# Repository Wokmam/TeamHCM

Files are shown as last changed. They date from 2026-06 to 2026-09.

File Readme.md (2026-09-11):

# 🤖 Team Born To Win - WRO Future Engineers

¡Bienvenidos al repositorio oficial de nuestro equipo! Aquí documentamos todo el desarrollo, código, diseño y avances para nuestra participación.

## 📸 Conoce al Equipo

<p align="center">
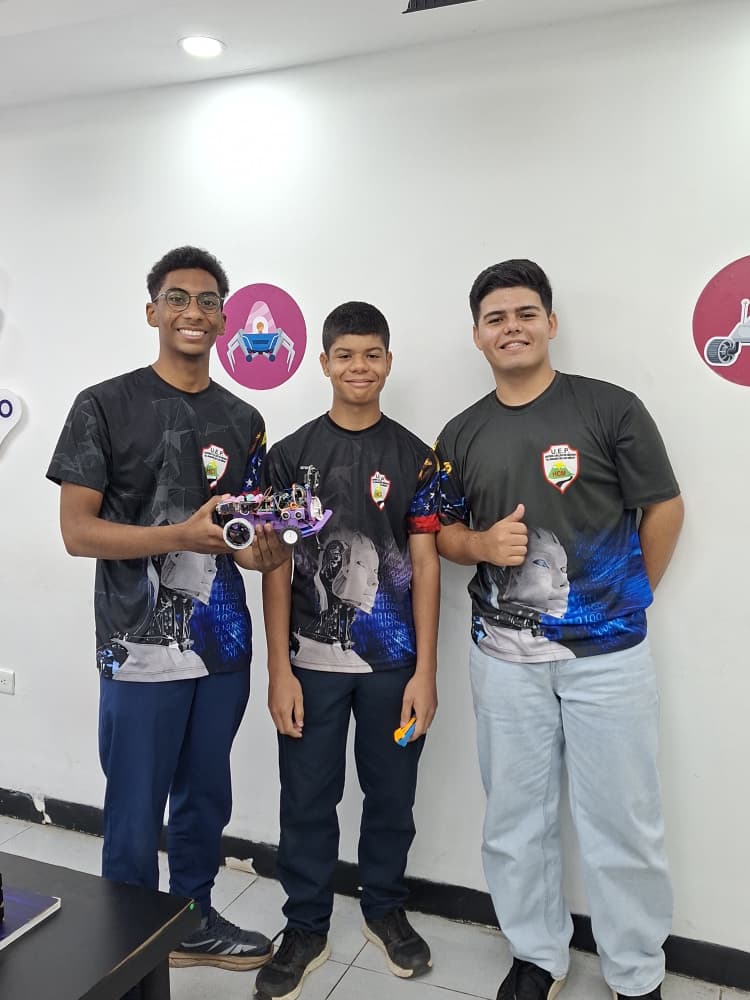
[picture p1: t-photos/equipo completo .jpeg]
Equipo completo Team HCM
  
</p>

 <p align="center">
  somos estudiantes de diferentes edades que nos reunimos con el objetivo de competir en la competencia WRO futuros ingenieros con nuestro proyecto
 </p> 
 
 ## Nuestro Equipo

<table align="center">
  <tr>
    <td align="center" width="33%">
      <h3>Carlos Armijo</h3>
      <p><b>Edad:</b> 17 años</p>
      <p><b>Rol:</b> Lógica de programación y estrategias</p>
    </td>
    <td align="center" width="33%">
      <h3>Julio Noguera</h3>
      <p><b>Edad:</b> 14 años</p>
      <p><b>Rol:</b> Gestión de GitHub, control de actualizaciones y estrategia</p>
    </td>
    <td align="center" width="33%">
      <h3>Miguel Salas</h3>
      <p><b>Edad:</b> 18 años</p>
      <p><b>Rol:</b> Mecánica, diseño 3D y electrónica</p>
    </td>
  </tr>
</table>

> *Puedes ver más detalles e imágenes en la carpeta [t-photos](t-photos/).*

# Índice de Contenidos — Team Born To Win (WRO Future Engineers)

1. [Presentación del Equipo](#1-presentación-del-equipo)
2. [World Robot Olympiad (WRO)](#2-world-robot-olympiad-wro)
3. [Arquitectura General del Sistema](#3-arquitectura-general-del-sistema)
4. [Sistema de Tracción (Tren Trasero)](#4-sistema-de-tracción-tren-trasero)
5. [Sistema de Dirección (Tren Delantero)](#5-sistema-de-dirección-tren-delantero)
6. [Diseño Estructural e Impresión 3D del Chasis](#6-diseño-estructural-e-impresión-3d-del-chasis)
7. [Sistema Electrónico y Sensores](#7-sistema-electrónico-y-sensores)
8. [Desafíos de la Competencia](#8-desafíos-de-la-competencia)
9. [Partes del Código (Firmware)](#9-partes-del-código-firmware)
10. [Lista de Componentes](#10-lista-de-componentes)

---

<h2>2. World Robot Olympiad (WRO)</h2>
<p align="center">
{4F88DD0A-A459-4292-9581-5FD236E6E98C}
</p>
World Robot Olympiad™ es una competencia temática en donde equipos de niños y jóvenes entre 8 y 22 años de edad medirán sus conocimientos, aplicando soluciones a problemas del mundo real, utilizando la Metodología STEAM, de la mano de la robótica educativa.<p>
<p>Dentro de la WRO, la categoría Futuros Ingenieros destaca por su enfoque práctico y evolutivo. Su objetivo principal es conectar a los estudiantes con los retos reales de la industria a través de la automatización. Al exigir un pensamiento analítico, esta división moldea a los líderes tecnológicos del mañana, transformando el conocimiento teórico en innovación pura.<p>

El desafío central de este año se enfoca en la conducción autónoma. Diseñar un coche capaz de tomar decisiones por sí mismo lleva la robótica educativa al siguiente nivel, forzando a los participantes a dominar herramientas de última generación y aportando un nivel de ingeniería y dinamismo.

<h2>Secciones</h2>

## 1. Arquitectura General del Sistema
El vehículo utiliza una configuración de **Tracción Trasera (RWD)** combinada con un sistema de **Dirección Delantera**. Esta disposición emula el comportamiento de un automóvil real.
<p align="center">
aa
</p>

## 2. Sistema de Tracción (Tren Trasero)

El tren trasero es el encargado de proveer el torque y velocidad necesarios para el desplazamiento del vehículo. Está compuesto por un motor principal y un mecanismo diferencial.

### 2.1. Actuador Principal: Motor DC con Encoder (600 RPM)
Para la propulsión se seleccionó un motor de corriente continua (DC) equipado con un encoder de cuadratura.
<table>
  <tr>    
    <td width="40%" align="center" valign="middle" bgcolor="#0d1117">
      51+JncrV17L _SX522_-removebg-preview
    </td>
    <td width="60%" valign="middle" bgcolor="#0d1117">
      <h3>Especificaciones:</h3>
      <ul>
        <li><strong>Voltaje Nominal:</strong> 12V</li>
        <li><strong>Velocidad:</strong> 600 RPM</li>
        <li><strong>Tipo de Encoder:</strong> Encoder de cuadratura (Efecto Hall) de fase A y B con 120 PPR en el eje de salida</li>
      </ul>
    </td>
  </tr>
</table>

* **Motivos de Selección:**
    * **Cálculo de Odometría:** El propósito fundamental del encoder es la odometría. Al contar los pulsos generados por las vueltas del motor, el firmware calcula con precisión cuántos centímetros ha avanzado el vehículo en la pista. Esto nos permite programar desplazamientos basados en distancias exactas.

### 2.2. Caja de Engranajes y Sistema Diferencial
La potencia del motor no va directo a las ruedas; pasa a través de una etapa de reducción y se distribuye mediante un diferencial mecánico.

<p align="center">
WhatsApp Image 2026-06-25 at 2 18 30 PM
</p>

* **Mecanismo Diferencial:** Se diseñó e implementó un diferencial de engranajes cónicos en el eje trasero.
* **Motivos de Selección e Implementación:**
    * **Impreso en 3D:** Todo el conjunto del mecanismo diferencial ha sido fabricado mediante impresión 3D utilizando filamento **PETG**. Se seleccionó este material debido a su alta resistencia al impacto y durabilidad superior frente al PLA.
    * **Rodamientos:** Para soportar el movimiento del diferencial, se integraron rodamientos. Estos ayudan a evitar atascos mecánicos, reducir la fricción y permitir un giro mucho más suave y eficiente del eje.
    * **Evitar derrapes:** En las curvas, la rueda interior recorre una distancia menor que la rueda exterior. Sin un diferencial, una de las ruedas se vería obligada a patinar, provocando pérdida de tracción y descalibración de la odometría basada en el encoder.

## 3. Sistema de Dirección (Tren Delantero)
En el sistema de dirección, la precisión es vital para que el robot no se desvíe de los ángulos deseados y mantenga trayectorias repetibles.
  
### 3.1. Actuador de Dirección: Servomotor
El control angular de las ruedas delanteras se realiza mediante un servomotor de alta precisión conectado a una geometría de dirección.

<table>
  <tr>    
    <td width="40%" align="center" valign="middle" bgcolor="#0d1117">
    bb0c992e-8172-4063-9124-5125c4acf2e3 __CR0_0_300_300_PT0_SX300_V1___-removebg-preview
    </td>
    <td width="60%" valign="middle" bgcolor="#0d1117">
      <h3>Especificaciones:</h3>
      <ul>
        <li><strong>Tipo:</strong> Digital</li>
        <li><strong>Velocidad:</strong> 0.12 sec/60° (4.8V)</li>
        <li><strong>Torque:</strong> 1.8 kg-cm (4.8V)</li>
        <li><strong>Voltaje:</strong> 5V</li>
        <li><strong>Rango de Operación:</strong> 0°-180°</li>
      </ul>
    </td>
  </tr>
</table>

* **Motivos de Selección:**
    * **Control de Posición preciso:** A diferencia de un motor DC común, el servomotor permite definir un ángulo exacto.
    * **Tipo de servomotor:** Se seleccionó específicamente un servomotor con piñonería metálica en lugar de uno con engranajes de plástico. En pruebas previas, los componentes de plástico experimentaban un desgaste excesivo debido al estrés mecánico, lo que provocaba un aumento crítico en la temperatura del actuador y fallos por rotura de dientes. Los engranajes metálicos ofrecen la tolerancia al torque y la disipación térmica necesarias para soportar las exigencias.

### 3.2. Geometría de Dirección (Principio de Ackerman)
El varillaje mecánico de la dirección delantera está diseñado siguiendo geométricamente el principio de **Ackerman**.

<p align="center">
parte delantera del carro
</p>

* **Justificación Técnica:**
    * **Estructura Impresa en 3D:** Al igual que el tren trasero, las varillas y las manguetas de la dirección están fabricados totalmente mediante impresión 3D en **PETG**.
    * **Rodamientos en Ruedas Delanteras:** Para mejorar la fluidez del movimiento, se incorporaron rodamientos en ambas ruedas delanteras. Esto disminuye la fricción al rodar, asegurando que las llantas delanteras giren mucho mejor y respondan mejor a los cambios de dirección.

### 4. Diseño Estructural e Impresión 3D del Chasis
La plataforma base del robot fue diseñada en Fusion360 completamente a medida y fabricada en su totalidad mediante impresión 3D utilizando filamento PETG. lo que le otorga una alta resistencia a los impactos y durabilidad.

El diseño en 3D conecta directamente los soportes impresos en 3D 
para el portabaterías, la PCB principal y los sensores ultrasónicos. Toda la unión de estos soportes, componentes electrónicos y sensores al chasis se realiza mediante tornillos. Esto asegura una fijación firme que evita vibraciones o desajustes.

<p align="center">
vehicle-botton
</p>

<table>
  <thead>
    <tr>
      <th align="center">Dimensión</th>
      <th align="left">Valor (CM)</th>
    </tr>
  </thead>
  <tbody>
    <tr>
      <td align="center" valign="middle">Largo</td>
      <td align="left" valign="middle">25</td>
      </td>
    </tr>
    <tr>
      <td align="center" valign="middle">Ancho</td>
      <td align="left" valign="middle">16.8</td>
      </td>
    </tr>
    <tr>
      <td align="center" valign="middle">Alto</td>
      <td align="left" valign="middle">10</td>
      </td>
    </tr>
  </tbody>
</table>

## 5. Sistema Electrónico y Sensores
Este apartado abarca la arquitectura electrónica del vehículo y los componentes seleccionados para la gestión de tareas y percepción del entorno.

<p align="center">
Esquema_conexiones
</p>

<hr style="border: none; border-top: 5px solid #30363d; margin: 20px 0;">

## Unidad de Procesamiento: Arduino Mega Pro Mini
Como placa de desarrollo seleccionamos el Arduino Mega Pro Mini, que se encarga de la lectura de sensores y la genereación de señales para los actuadores.

Se seleccionó esta variante específica debido a su de forma sumamente reducida en comparación con el Arduino Mega convencional, lo que permite integrarlo de manera eficiente en el chasis sin comprometer espacio ni añadir peso innecesario. A pesar de su tamaño compacto, conserva la totalidad de pines digitales y analógicos del microcontrolador ATmega2560, ofreciendo la conectividad necesaria para gestionar múltiples sensores y actuadores de forma simultánea. Asimismo, su diseño plano facilita soldarle pines header macho para conectarlo a pines header hembra conectaods en nuestra PCB personalizada, eliminando el uso de cables propensos a falsos contactos por las vibraciones del coche. Todo esto se complementa con una excelente relación costo-beneficio, asegurando un hardware potente, fiable y económico para el desarrollo del proyecto.

En la arquitectura de nuestro sistema, el Arduino Mega Pro Mini funciona como el cerebro del robot, procesando las entradas del sistema de visión ESP32-CAM, la IMU de 6 ejes MPU-6050 y tres sensores de Ultrasonidos HC-SR04, al tiempo que ejecuta algoritmos y genera salidas de control precisas para el controlador de motor y el ServoMotor.

<table>
  <tr>    
    <td width="40%" align="center" valign="middle" bgcolor="#0d1117">
    ard-removebg-preview
    </td>
    <td width="60%" valign="middle" bgcolor="#0d1117">
      <h3>Especificaciones:</h3>
      <ul>
        <li><strong>Microcontrolador:</strong> ATmega2560</li>
        <li><strong>Consumo mA:</strong> 20mA</li>
        <li><strong>Entradas Analógicas:</strong> 16</li>
        <li><strong>Pines Digitales E/S:</strong> 54 (de los cuales 15 son salidas PWM)</li>
        <li><strong>Voltaje de Operación:</strong> 5V</li>
      </ul>
    </td>
  </tr>
</table>

<hr style="border: none; border-top: 5px solid #30363d; margin: 20px 0;">

## 5.2. Sensores de Distancia: Ultrasonidos HC-SR04

El cálculo de las distancias hacia los límites de la pista se gestiona mediante un conjunto de sensores de ultrasonidos HC-SR04 ubicados de forma estratégica en la parte frontal del coche. Estos componentes operan emitiendo una ráfaga de ondas acústicas de alta frecuencia que viajan por el aire hasta reflejarse en las superficies fijas del entorno y regresar al receptor. A través del tiempo que tarda este eco en retornar, el microcontrolador calcula con gran precisión la distancia en centímetros hacia los muros.

<p align="center">
Gemini_Generated_Image_czb582czb582czb5
</p>

En la lógica de navegación de nuestro coche, el sensor central se encarga de monitorizar el espacio libre al frente, lo que resulta crítico para identificar la aproximación hacia las paredes frontales de la pista. Por su parte, los dos sensores laterales evalúan la proximidad de los muros izquierdo y derecho. La integración conjunta de estas tres lecturas permite al firmware saber en qué salida se encuentra para ejecutar una ruta ya hecha. Al estar atornillados con firmeza en los soportes impresos en 3D que están puestos en el chasis, se garantiza que los ángulos de apertura inferiores a 15° se mantengan estables y libres de las vibraciones propias del motor.

<table>
  <tr>    
    <td width="40%" align="center" valign="middle" bgcolor="#0d1117">
      descarga-removebg-preview (1)
    </td>
    <td width="60%" valign="middle" bgcolor="#0d1117">
      <h3>Especificaciones Técnicas:</h3>
      <ul>
        <li><strong>Voltaje de operación:</strong> 5V</li>
        <li><strong>Rango de medición:</strong> 2 cm a 400 cm</li>
        <li><strong>Precisión:</strong> ±3 mm</li>
        <li><strong>Ángulo de apertura:</strong> Menor a 15°</li>
        <li><strong>Corriente de trabajo:</strong> 15 mA</li>
      </ul>
    </td>
  </tr>
</table>

<hr style="border: none; border-top: 5px solid #30363d; margin: 20px 0;">

## 5.3. Unidad de Medición Inercial (IMU): MPU6050
La estabilidad angular y la orientación espacial del vehículo están reguladas por la unidad de medición inercial MPU6050. Este dispositivo integra un giroscopio de tres ejes y un acelerómetro de tres ejes en un único chip, permitiendo capturar con precisión los cambios de velocidad y las variaciones en la rotación del coche sobre la pista. La comunicación con el microcontrolador central se realiza de manera eficiente a través del protocolo I2C, lo que asegura una transmisión rápida de los datos inerciales recolectados en tiempo real.

<p align="center">
images
</p>

La implementación de la IMU es fundamental para el sistema de navegación del vehículo, ya que cumple la función de corregir las desviaciones en la trayectoria recta. Aunque los encoders del motor miden los centímetros avanzados, factores físicos como el deslizamiento de las llantas o las imperfecciones del suelo pueden hacer que el carro pierda el rumbo. El MPU6050 monitorea constantemente el ángulo de guiñada (*yaw*), detectando cualquier giro involuntario y permitiendo que el firmware realice ajustes inmediatos en el servomotor de dirección para contrarrestar el desvío y mantener al robot alineado perfectamente con la pista.

<table>
  <tr>    
    <td width="40%" align="center" valign="middle" bgcolor="#0d1117">
      mpu6050_3-axis_acceleration_gyroscope_6dof_module_2-removebg-preview
    </td>
    <td width="60%" valign="middle" bgcolor="#0d1117">
      <h3>Especificaciones Técnicas:</h3>
      <ul>
        <li><strong>Voltaje de Operación:</strong> 3.3V - 5.0V</li>
        <li><strong>Grados de Libertad:</strong> 6 ejes (3 ejes acelerómetro, 3 ejes giroscopio)</li>
        <li><strong>Rango del Giroscopio:</strong> ±250, ±500, ±1000, ±2000 °/seg</li>
        <li><strong>Rango del Acelerómetro:</strong> ±2g, ±4g, ±8g, ±16g</li>
        <li><strong>Protocolo de Comunicación:</strong> I2C</li>
      </ul>
    </td>
  </tr>
</table>

**Conexión electrónica**

**Arreglo de alimentación y consumo**
Estamos trabajando con 4 baterías en una conexión mixta, con lo cual nos referimos a que están conectadas en serie y en paralelo. Vamos a llamar al primer grupo de baterías como Grupo A y a las otras dos baterías como Grupo B. Las dos baterías de cada grupo están conectadas entre sí en paralelo, y luego el Grupo A y el Grupo B están conectados en serie. Esto nos proporciona una corriente de 4 A, equivalente a 4000 mA, y un voltaje de 8 V.

Tenemos un regulador de voltaje elevador y reductor o *step-up/down*, el cual es muy práctico ya que permite subir y bajar el voltaje. El elevador está conectado desde el polo positivo y el negativo de las baterías. Desde este mismo positivo donde se alimenta el elevador existe un nodo conectado a un regulador de 5 V, y desde este regulador alimentamos el Arduino Mega Pro Mini. Además, contamos con un interruptor ubicado en la línea positiva que controla el encendido de todos los componentes.

**Etapa de potencia y actuadores**
El elevador de voltaje está ajustado a 12 V. Desde esos 12 V que ofrece el elevador alimentamos el módulo puente H L298N. La salida del puente H está conectada a un motor DC con encoder. En el Arduino tenemos conectados los pines de control IN1 e IN2, mientras que el pin ENA está conectado al pin 8 del Arduino. Usamos el pin 8 por ser un pin PWM, lo que nos permite modificar el ancho de pulso y así ajustar la velocidad del motor según sea necesario.

<p align="center">
  l298n
</p>

Tenemos dos LED: uno rojo y uno azul. El ánodo del LED rojo está conectado al pin 5 del Arduino y el ánodo del LED azul está conectado al pin 9. Ambos LED tienen su cátodo conectado a GND, que es el polo negativo del Arduino. También tenemos conectado un servomotor MG90S con engranajes metálicos, el cual proporciona un torque mayor al SG90 tradicional. Este servo está conectado al pin 7 del Arduino, que es un pin PWM. El servomotor se alimenta desde el regulador de 5 V que alimenta al Arduino, desde donde sale un nodo.

**Sensores y componentes adicionales**
Tenemos conectados los sensores de ultrasonidos a los lados y en el centro. El sensor del lado izquierdo está conectado a los pines 31 y 30, el del centro a los pines 27 y 29, y el del lado derecho a los pines 23 y 25.

También tenemos un giroscopio conectado al pin 20 para la línea SDA y al pin 21 para la línea SCL. Contamos con un pulsador normalmente abierto conectado al pin 28 del Arduino en configuración *pull-down*. Finalmente, hay un capacitor de 1000 microfaradios en el servomotor y otro de 470 microfaradios en el Arduino Mega Pro Mini.

<p align="center">
  hc-sr04
</p>

<h2>🎯 Desafíos de la Competencia</h2>
<table align="center" width="100%">
  <tr>
    <td width="50%" align="center" valign="top" bgcolor="#0d1117">
      <br>
      <h3>🔗 Desafío Abierto</h3>
      <a href="https://youtu.be/Df2YxnnMeV0?si=AwDFZAtFiafpjhe3">
        Open Challenge Roun
      </a>
      <br><br>
      <a href="https://youtu.be/Df2YxnnMeV0?si=AwDFZAtFiafpjhe3">Ver Ronde de Desafío Abierta</a>
      <br><br>
      <p><i>Navegación autónoma mediante IMU y sensores de distancia para completar vueltas y estacionamiento de de forma precisa</i></p>
    </td>
    <td width="50%" align="center" valign="top" bgcolor="#0d1117">
      <br>
      <h3>🔗 Desafío de Obstaculos</h3>
      <a href="URL">
        Obstacle Challenge Round
      </a>
      <br><br>
      <a href="URL">Ronda de Desafío Cerrada</a>
      <br><br>
      <p><i>Cumbia</i></p>
    </td>
  </tr>
</table>

<h2>Partes del codigo</h2>

## control de los motores

```cpp

#define ENA 8
#define IN1 4
#define IN2 6
int velocidadMotor = 255;

void setup() {
  pinMode(ENA, OUTPUT);
  pinMode(IN1, OUTPUT);
  pinMode(IN2, OUTPUT);
}

void loop() {
  digitalWrite(IN1, HIGH);
  digitalWrite(IN2, LOW);
  analogWrite(ENA, velocidadMotor);
}
```
esta parte del codigo se encarga de controlar el  motor para despues integrarlo a las variables 

## control del servo motor y giroscopio
```cpp
#include <Wire.h>
#include <MPU6050_tockn.h>
#include <Servo.h>

#define PIN_SERVO 7
MPU6050 mpu(Wire);
Servo myservo;
float yaw, setpoint = 0, centroServo = 82, Kp = 0.8;

void setup() {
  Wire.begin(); mpu.begin(); myservo.attach(PIN_SERVO);
  myservo.write(centroServo);
}

void loop() {
  mpu.update();
  yaw = mpu.getAngleZ();
  float error = setpoint - yaw;
  float salida = Kp * error;
  int anguloServo = constrain(centroServo + salida, 71, 93);
  myservo.write(anguloServo);
}
```
esta parte del codigo se encarga de ubicar el sentido del carro para hacer que en las variables puedan girar gracias al servo motor

# Sistema de Ultrasonidos (NewPing)

El robot utiliza **tres sensores ultrasónicos** gestionados a través de la librería `NewPing` para medir distancias de manera eficiente, detectar posiciones de referencia en la pista y asistir en el centrado lateral dentro de los pasillos.

## 📌 Pines de Conexión

| Sensor | Definición en Código | Pin Trigger (Trig) | Pin Echo (Echo) | Descripción / Función |
| :--- | :--- | :--- | :--- | :--- |
| **Izquierdo** | `IZ` | `31` | `30` | Medición lateral izquierda y cálculo de error de centrado. |
| **Medio (Frontal)** | `FE` | `27` | `29` | Detección frontal de obstáculos y control de distancia de frenado. |
| **Derecho** | `DE` | `23` | `25` | Medición lateral derecha y cálculo de error de centrado. |

* **Distancia Máxima Configurada:** `400 cm` (`Max_Dist` definido por `#define Max_Dist 400`).

---

## ⚙️ Funciones Principales

### 1. Actualización No Bloqueante (`actualizarDistancias`)
Para evitar que las demoras de los pulsos ultrasónicos detengan la ejecución del bucle principal y afecten la lectura de la IMU y los motores, las lecturas se actualizan mediante un intervalo de tiempo controlado por `millis()`:
* **Intervalo de muestreo:** `20 ms` (`const int intervaloPing = 20`).
* **Variables globales actualizadas:** `distIz`, `distDe` y `distFe`.

```cpp
void actualizarDistancias() {
  if (millis() - ultimoPing >= intervaloPing) {
    distIz = IZ.ping_cm();
    distDe = DE.ping_cm();
    distFe = FE.ping_cm();
    ultimoPing = millis();
  }
}
## pasos contados de los motores 

#define Clk 3
#define Dt 2
volatile long ticks = 0;
const float CM_POR_TICK = 0.01;

void setup() {
  //
  attachInterrupt(digitalPinToInterrupt(Clk), ENCODER, CHANGE);
}

void ENCODER() {
  int A = digitalRead(Clk); int B = digitalRead(Dt);
  // Lógica de cuadratura para sumar/restar ticks
  if (A == 1) ticks += (B == 0) ? 1 : -1; 
}

float obtenerDistanciaCm() {
  long t; noInterrupts(); t = ticks; interrupts();
  return t * CM_POR_TICK;
}
```
Con esta parte del codigo nos permite saber cuando girar ya que podemos calcular la distancia recorrida.

## funciones 
```cpp
void posicion1velocidad200() {
  float distancia = obtenerDistanciaCm();
  if (distancia >= 0 && distancia <= 22.56) {
    controlarServoIMU(); controlarMotor200();
    modoCentradoActivo = false; setpoint = 0; // Recta inicial
  } else if (distancia >= 22.56 && distancia <= 48.21) {
    controlarServoIMU(); controlarMotor200();
    modoCentradoActivo = false; setpoint = 180; // Curva
  } else if (distancia >= 48.21 && distancia <= 70.77) {
    controlarServoIMU(); controlarMotor200();
    modoCentradoActivo = true; setpoint = 180; // Curva centrando
  }

}
void posicion2velocidad200() { /* Intervalos y setpoints para ruta 2 */ }
void posicion3velocidad200() { /* Intervalos y setpoints para ruta 3 */ }
void posicion4adelante()       { /* Intervalos y setpoints para ruta 4 */ }
void posicion5adelante()       { /* Intervalos y setpoints para ruta 5 */ }
void posicion6adelante()       { /* Intervalos y setpoints para ruta 6 */ }
```

Esta parte del codigo tiene la capacidad de decidir que ruta hace el robot de pendiendo de los valores del  giroscopio y los sensores de ultra sonido.

## pulldown
```cpp
void loop() {
  if (pulldowm == 1) {
    if (estadoposinverso == 1) posicion1inverso();
 
  } else {
    if (estadopos == 1) posicion1velocidad200();

  }
}

void posicion1inverso() {
  float distancia = obtenerDistanciaCm();
  if (distancia >= 22.56 && distancia <= 48.21) {
    setpoint = -180; 
}
```
Esta parte del código permite hacer que el código pueda inicializar los proceso de ubicación y arranque del carro.
<h2>Lista de Componentes</h2>

<table>
  <thead>
    <tr>
      <th align="center">Cantidad</th>
      <th align="left">Nombre</th>
      <th align="center">Foto</th>
    </tr>
  </thead>
  <tbody>
    <tr>
      <td align="center" valign="middle">1</td>
      <td align="left" valign="middle">Arduino Mega Pro Mini</td>
      <td align="center">
        ard-removebg-preview
      </td>
    </tr>
    <tr>
      <td align="center" valign="middle">1</td>
      <td align="left" valign="middle">MPU6050</td>
      <td align="center">
        MPU6050
      </td>
    </tr>
    <tr>
      <td align="center" valign="middle">1</td>
      <td align="left" valign="middle">Puente H l298n</td>
      <td align="center">
        l298n
    </tr>
         <td align="center" valign="middle">1</td>
      <td align="left" valign="middle">esp32cam</td>
      <td align="center">
        esp32cam
        </td>
      </tr>
   </tr>
        <td align="center" valign="middle">3</td>
      <td align="left" valign="middle">hc-sr04</td>
      <td align="center">
        hc-sr04
        </td>
      </tr>
   </tr>
       <td align="center" valign="middle">1</td>
      <td align="left" valign="middle">motor dc con encoder</td>
      <td align="center">
        l298n 
      </td>
    </tr>
       <td align="center" valign="middle">1</td>
      <td align="left" valign="middle">mg90s</td>
      <td align="center">
        mg90s 
      </td>
    </tr>
       <td align="center" valign="middle">1</td>
      <td align="left" valign="middle">vaquelita perforada (15x9)</td>
      <td align="center">
        vaquelita perforada grande
      </td>
    </tr>
         <td align="center" valign="middle">1</td>
      <td align="left" valign="middle">led rojo</td>
      <td align="center">
        led rojo
      </td>
    </tr>
          <td align="center" valign="middle">1</td>
      <td align="left" valign="middle">led azul</td>
      <td align="center">
        led rojo
      </td>
    </tr>
           <td align="center" valign="middle">1</td>
      <td align="left" valign="middle">espadines macho</td>
      <td align="center">
        espadines macho
      </td>
    </tr>
             <td align="center" valign="middle">1</td>
      <td align="left" valign="middle">espadines hembras</td>
      <td align="center">
        espadines hembras
      </td>
    </tr>
              <td align="center" valign="middle">1</td>
      <td align="left" valign="middle">capacitor</td>
      <td align="center">
        capacitor
      </td>
    </tr>
               <td align="center" valign="middle">1</td>
      <td align="left" valign="middle">regulador de voltaje 5v</td>
      <td align="center">
        regulador
      </td>
    </tr>
      <tr>
      <td align="center" valign="middle">4</td>
      <td align="left" valign="middle">Baterias 18650</td>
      <td align="center">
        litio
      </td>
    </tr>
    <tr>
      <td align="center" valign="middle">1</td>
      <td align="left" valign="middle">Botón</td>
      <td align="center">
        button
      </td>
    </tr>
  </tbody>
</table>

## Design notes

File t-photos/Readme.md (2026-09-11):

# 👥 Conoce al Team HCM

¡Bienvenidos a la sección de fotos y miembros del equipo! Aquí presentamos oficialmente a los integrantes que hacen posible este proyecto para la competición **WRO Future Engineers**.

---

## 👨‍💻 Integrantes del Equipo

<table align="center">
  <tr>
    <td align="center" width="33%">
      <h3>Carlos Armijo</h3>
      <p><b>Edad:</b> 17 años</p>
      <p><b>Rol:</b> Lógica de programación y estrategias</p>
    </td>
    <td align="center" width="33%">
      <h3>Julio Noguera</h3>
      <p><b>Edad:</b> 14 años</p>
      <p><b>Rol:</b> Gestión de GitHub, control de actualizaciones y estrategia</p>
    </td>
    <td align="center" width="33%">
      <h3>Miguel Salas</h3>
      <p><b>Edad:</b> 18 años</p>
      <p><b>Rol:</b> Mecánica, diseño 3D y electrónica, programación</p>
    </td>
  </tr>
</table>

---

## 📸 Foto Oficial del Equipo

<p align="center">
  Equipo completo Team HCM
</p>

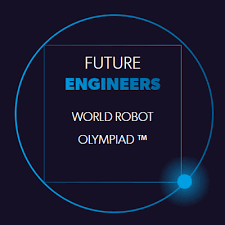
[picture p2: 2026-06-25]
images/WRO.png

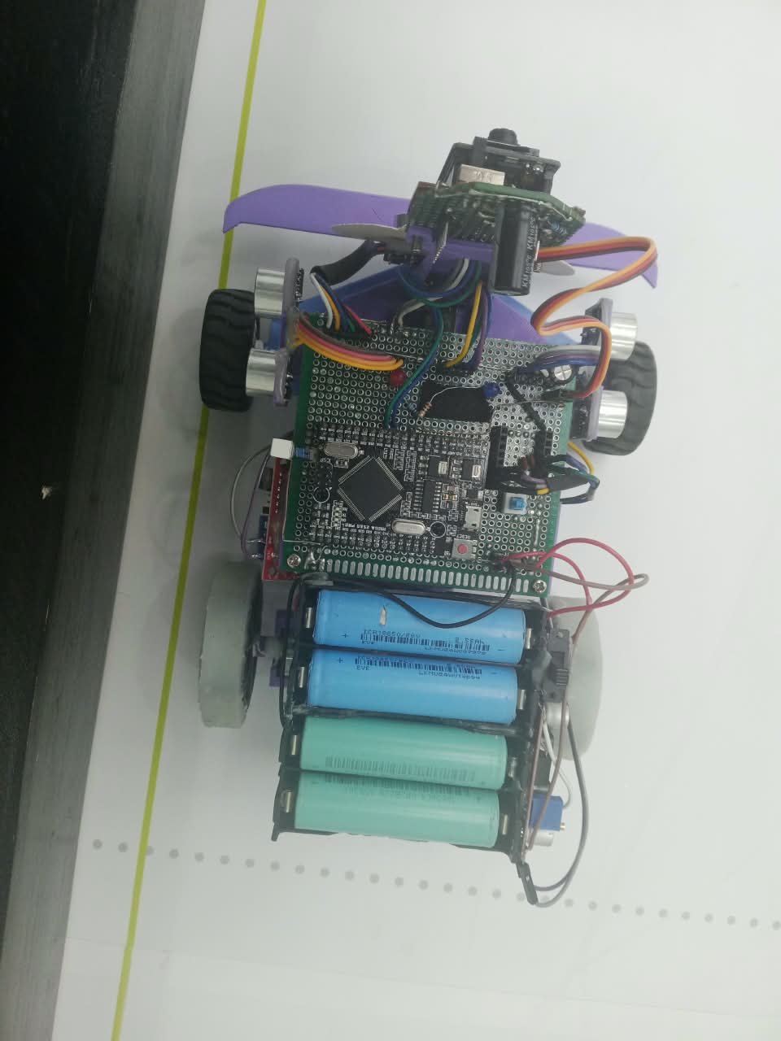
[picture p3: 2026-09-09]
v-photos/parte superior del carro.jpeg

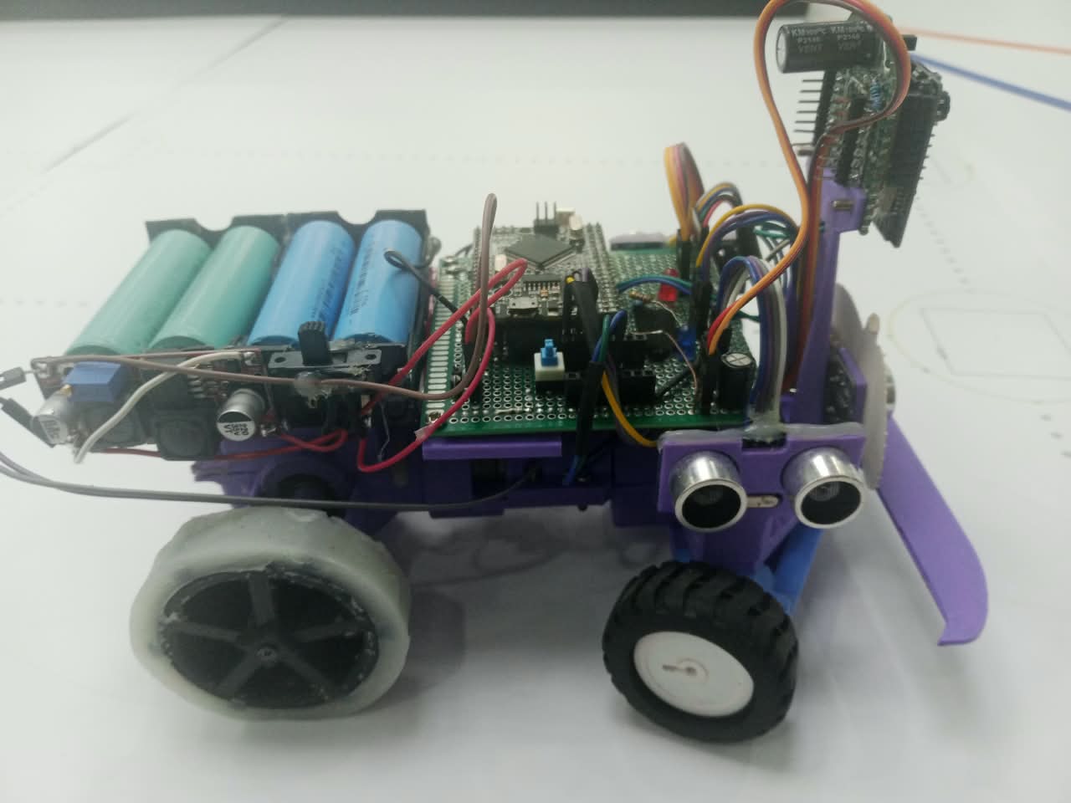
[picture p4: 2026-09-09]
v-photos/parte izquierda del carro.jpeg

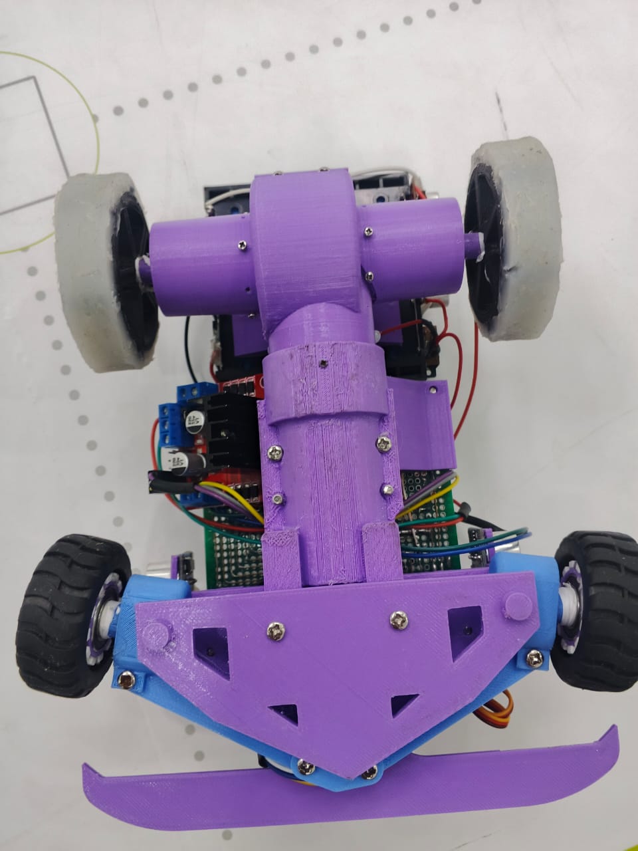
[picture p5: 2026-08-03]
v-photos/parte inferior del carro.jpeg

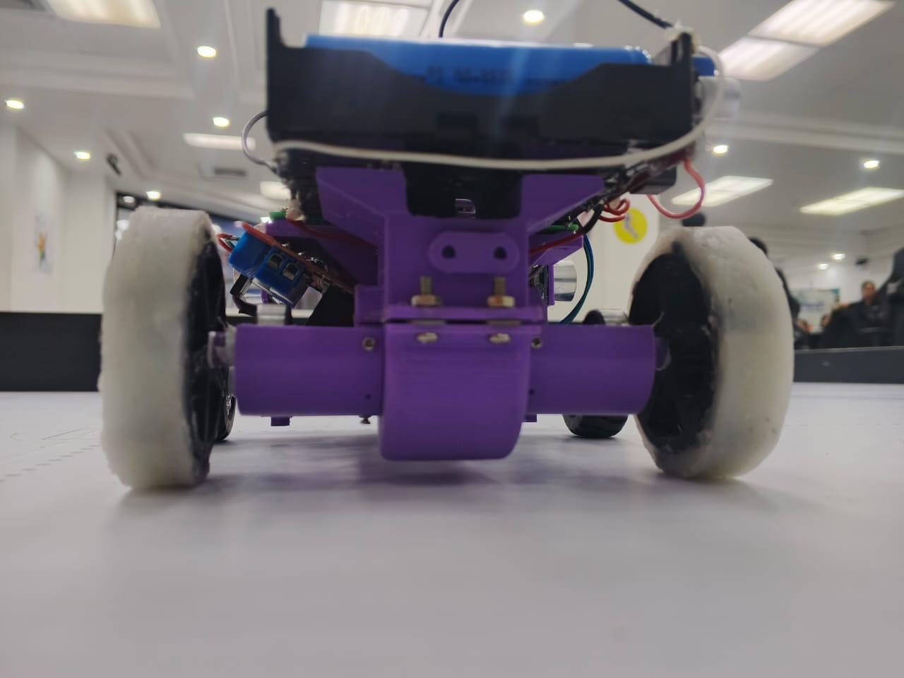
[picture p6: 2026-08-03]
v-photos/parte trasera del carro.jpeg

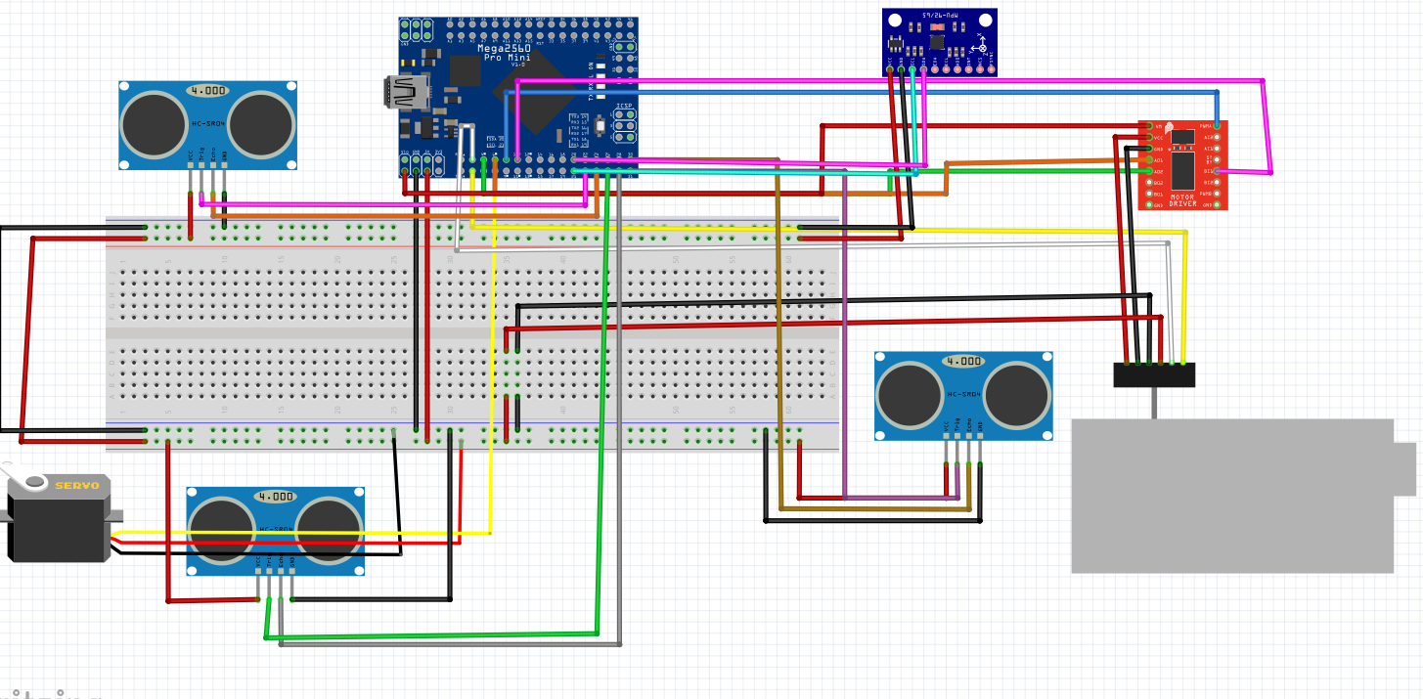
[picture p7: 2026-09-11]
Schemes/Captura de pantalla 2026-06-27 235005.png

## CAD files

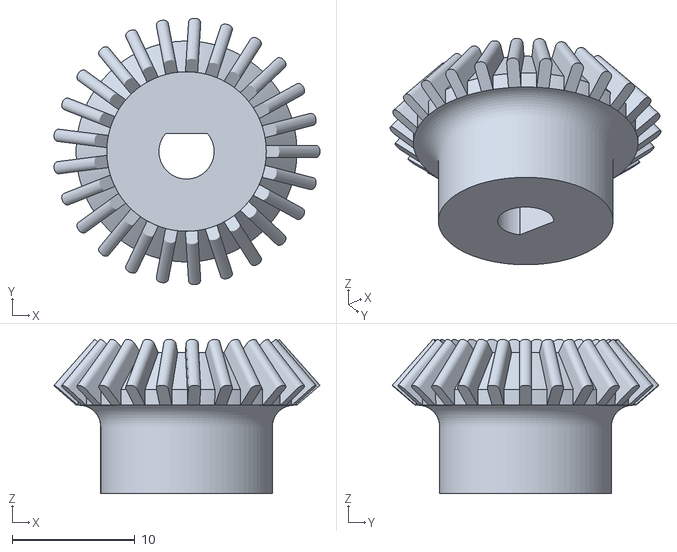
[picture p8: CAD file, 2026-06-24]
3D-Models/0.8.stl
21.7 x 21.7 x 12.6

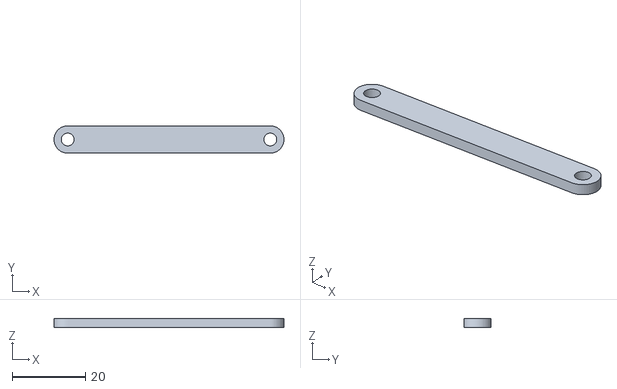
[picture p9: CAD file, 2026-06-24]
3D-Models/sujeta servo l.stl
63.0 x 7.50 x 2.40

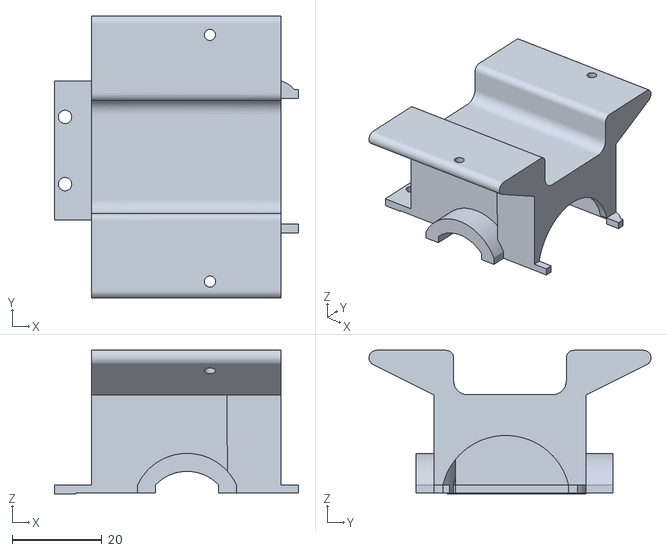
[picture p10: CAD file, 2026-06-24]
3D-Models/sosten bateria .stl
54.5 x 62.9 x 32.0

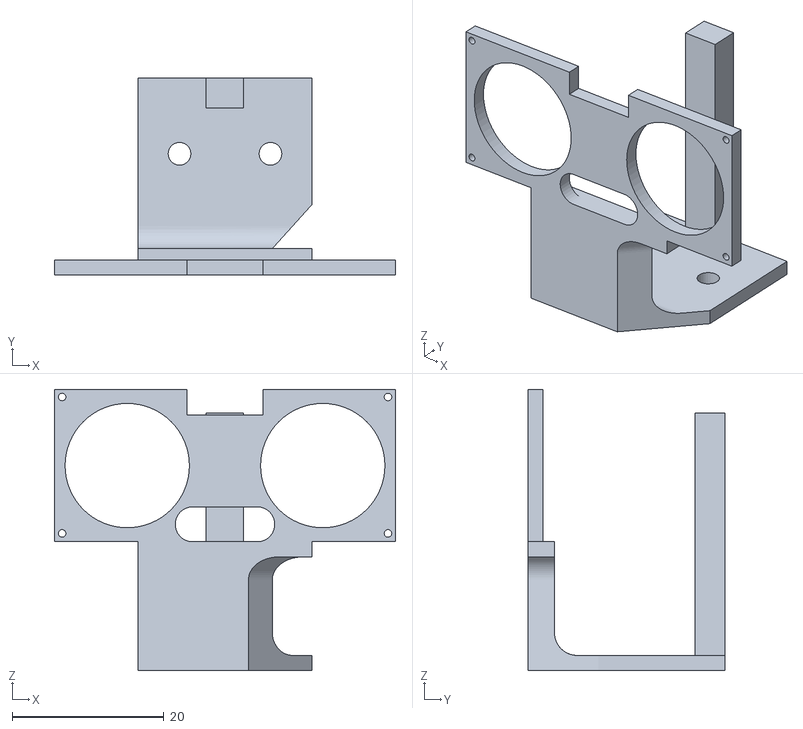
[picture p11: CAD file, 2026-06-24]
3D-Models/Soporte ultrasonido derecha.stl
45.0 x 26.0 x 37.1

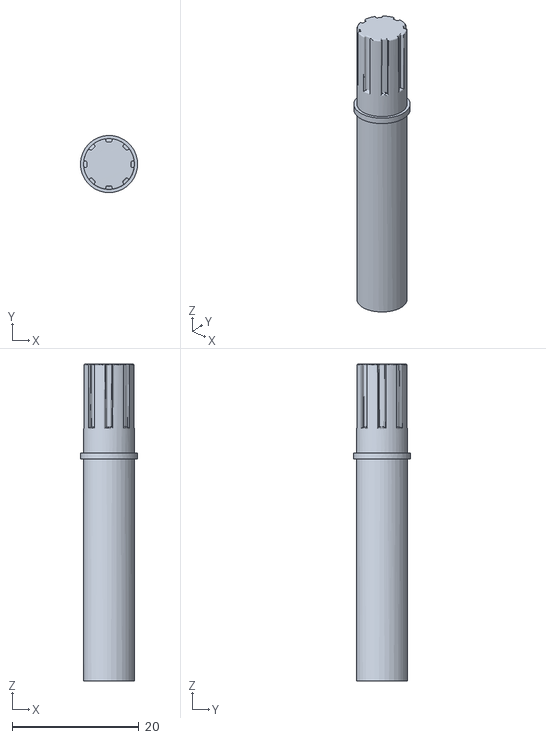
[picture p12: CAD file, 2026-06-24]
3D-Models/obj_2_AKS.STL.stl
9.00 x 9.00 x 50.0

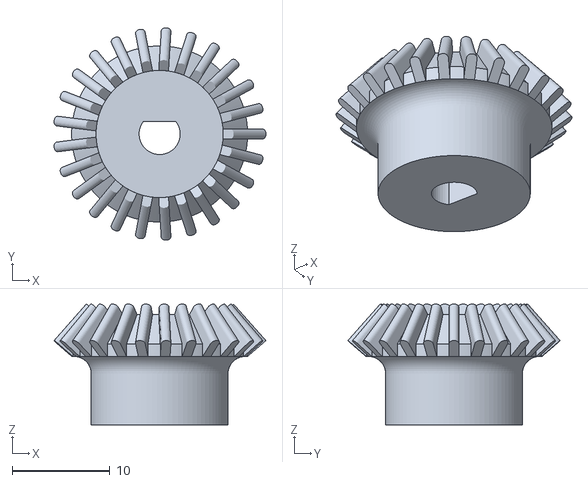
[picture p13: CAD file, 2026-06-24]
3D-Models/MECAP -1.stl
21.7 x 21.7 x 12.4

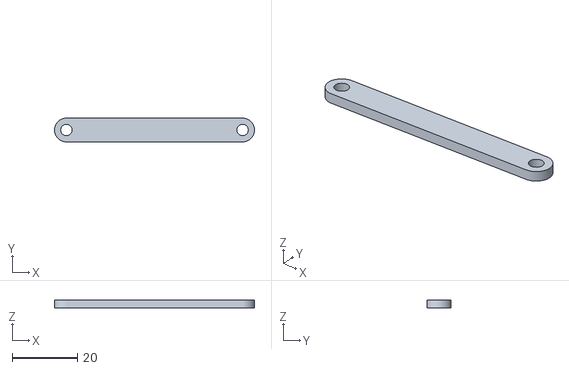
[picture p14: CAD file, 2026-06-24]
3D-Models/sujeta servo mas rueda.stl
61.3 x 7.30 x 2.40

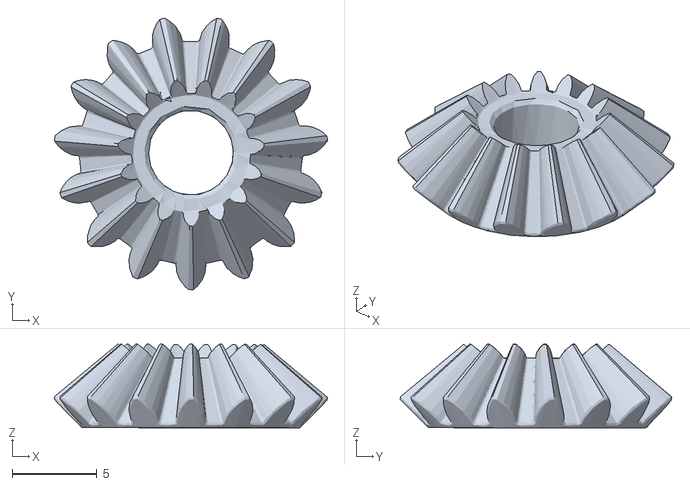
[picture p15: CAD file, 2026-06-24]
3D-Models/obj_6_PLANET DİŞLİ.STL.stl
16.1 x 16.1 x 4.96

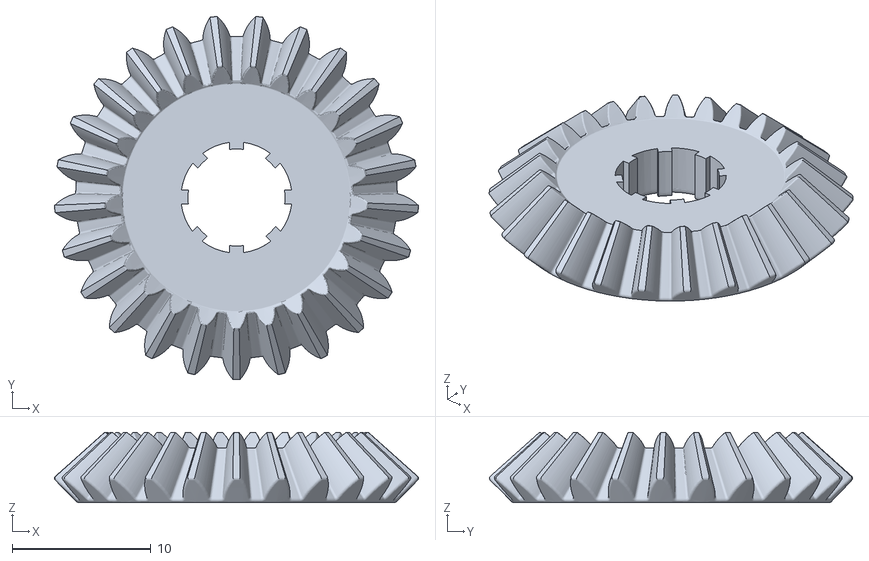
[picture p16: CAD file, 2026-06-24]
3D-Models/obj_7_YANAK DİŞLİSİ.STL.stl
26.2 x 26.2 x 5.06

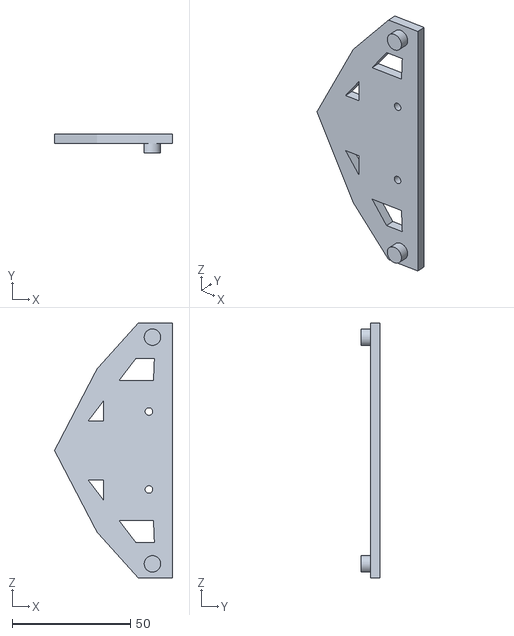
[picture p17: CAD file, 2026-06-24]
3D-Models/abajo servo.stl
50.0 x 8.00 x 108.0

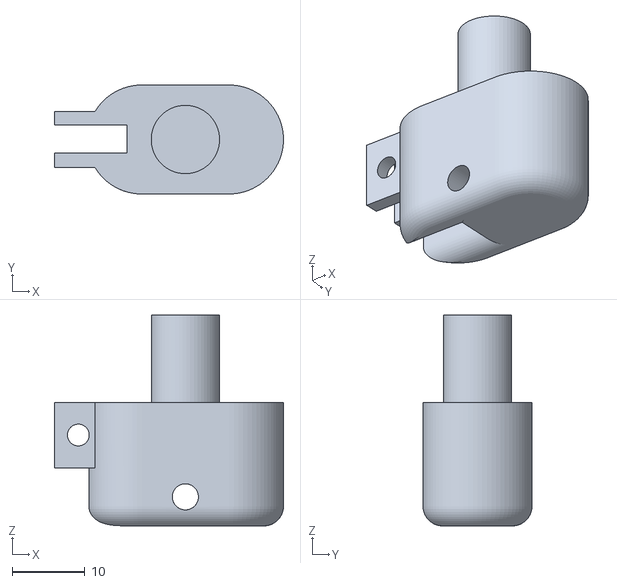
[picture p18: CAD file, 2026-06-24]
3D-Models/trn superior sosten is.stl
31.5 x 15.0 x 29.0

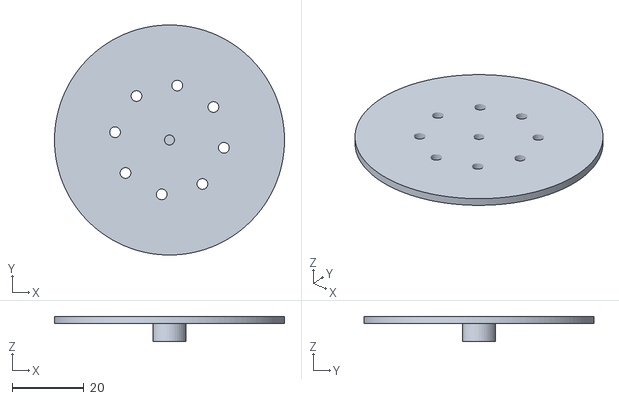
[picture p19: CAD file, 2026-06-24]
3D-Models/tapa molde wro.stl
64.2 x 64.2 x 7.00

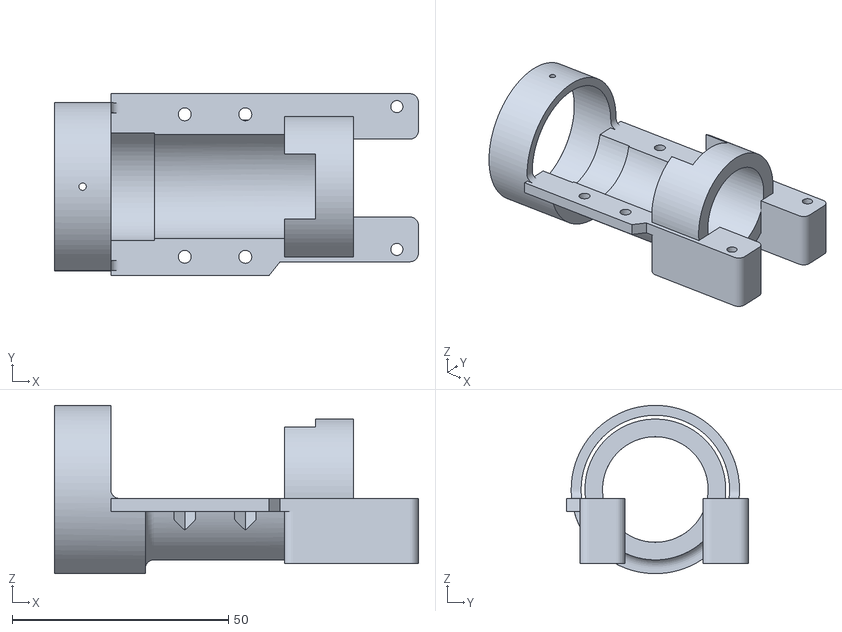
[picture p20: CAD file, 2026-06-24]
3D-Models/chasis central wro motor mas tren etc.stl
84.1 x 42.0 x 38.9

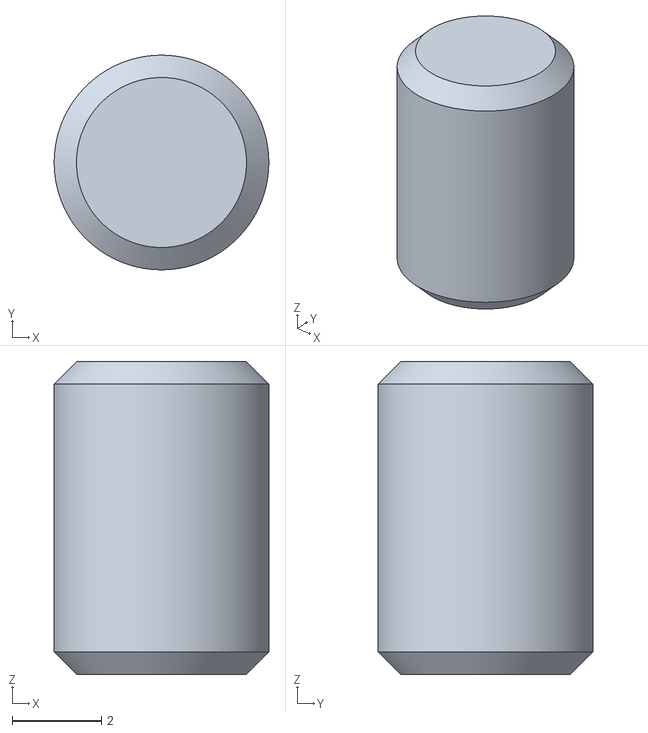
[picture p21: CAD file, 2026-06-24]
3D-Models/obj_9_pim.STL.stl
4.80 x 4.80 x 7.00

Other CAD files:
3D-Models/base bateria wro.stl
3D-Models/base de electronica.stl
3D-Models/chasis wro sosten de la mitad.stl
3D-Models/obj_11_pim.STL.stl
3D-Models/MACA PUNTA.stl
3D-Models/MACAP-1.5.stl
3D-Models/MECANISMO DEL MOTOR CON ENCODER PIESA DEL DIFERENCIAL (~recovered).f3d
3D-Models/MECANISMO DEL MOTOR CON ENCODER PIESA DEL DIFERENCIAL.stl
3D-Models/PORTA MOTOR.stl
3D-Models/PORTA MOTOR1.stl
3D-Models/PUNTA DEL MECANISMO.stl
3D-Models/Soporte Ultrasonido frontal.stl
3D-Models/base bateria wro v1.stl
3D-Models/base de la bateria wro.stl
3D-Models/bateria wro v2.stl
3D-Models/chasi9s parte de arriva .stl
3D-Models/chasis arriva servo.stl
3D-Models/dif largo sosten de rueda.stl
3D-Models/dif sosten dela rueda.stl
3D-Models/dif.stl
3D-Models/molde de la rueda tren delantero.stl
3D-Models/molde wro.stl
3D-Models/mpu6050wro.stl
3D-Models/obj_10_PLANET DİŞLİ.STL.stl
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

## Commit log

2026-06-25 Update Readme with product details and images
    Added product descriptions and images for Raspberry Pi and Logitech Webcam.
2026-06-25 Update image and specifications in Readme.md
    Updated image source and modified operating voltage description.
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2026-06-25 Revise N20 Motor Specifications in Readme
    Updated motor specifications in the documentation.
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2026-06-25 Revise motor selection reasons and odometry details
    Updated the selection reasons for the motor and added details about odometry calculation.
2026-06-25 Fix formatting of odometry calculation description
2026-06-25 Update Readme with motor specifications table
    Added specifications table for the DC motor with encoder.
2026-06-25 Modify image tag for motor specifications
    Updated image tag in Readme.md to remove height attribute.
2026-06-25 Enhance Readme with components table
    Added a table with components and their descriptions, including images for Raspberry Pi 4, MPU6050, and H-Bridge TB6612FNG.
2026-06-25 Update Raspberry Pi image and clean up Readme
    Updated the Raspberry Pi image and removed unnecessary lines from the table.
2026-06-25 Adjust image size for Raspberry Pi 4 in README
    Updated image dimensions for Raspberry Pi 4 Model B in the README.
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2026-06-25 Adjust image size in Readme.md
    Updated image size in the gearbox and differential system section.
2026-06-25 Remove image from gearbox and differential section
    Removed an image tag from the documentation section about the gearbox and differential system.
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2026-06-25 Rename Soporte Ultrasonido frontal.st to Soporte Ultrasonido frontal.stl
    [Soporte Ultrasonido frontal.stl]
2026-06-25 Rename Soporte Ultrasonido frontal.stl to 3D-Models/Soporte Ultrasonido frontal.stl
    [Soporte Ultrasonido frontal.stl]
2026-06-25 Rename ultrasonico esquierda derecha.stl to Soporte ultrasonido derecha.stl
    [Soporte ultrasonido derecha.stl]
2026-06-25 Revise servomotor selection reasons in Readme
    Updated the section on selection reasons for using a servomotor, emphasizing the advantages of metal gears over plastic ones in terms of thermal and mechanical robustness.
2026-06-25 Clarify autonomous steering precision requirements
    Updated the section on autonomous steering for clarity.
2026-06-25 Revise technical justifications and component details
    Updated technical justifications and component descriptions in Readme.md, including details on 3D printing materials and mechanisms.
2026-06-25 Remove mobility and traction system description
    Removed the section describing the mobility and traction system, while retaining the general architecture and details about the differential mechanism and steering system.
2026-06-25 Update steering system description for clarity
    Clarified the description of the steering system in the Readme.
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2026-06-25 Fix typos in Readme.md
    Corrected typographical errors in the specifications and odometry sections of the Readme.
2026-06-25 Refine wording in Readme for clarity
    Removed redundant wording in odometry and differential sections for clarity.
2026-06-26 Replace Raspberry Pi 4 Model B with Arduino Mega Pro Mini
2026-06-27 Add electronic systems and sensors section to Readme
    Added section on electronic systems and sensors with components list.
2026-06-27 Insert image in Readme for electronic system section
    Added an image to the 'Sistema Electrónico y Sensores' section.
2026-06-28 Add images to Sistema Electrónico y Sensores section
    Added images to the electronic system and sensors section.
2026-06-28 Enhance Readme with Arduino Mega Pro Mini details
    Added detailed description and specifications for Arduino Mega Pro Mini.
2026-06-28 Enhance Arduino Mega Pro Mini section in Readme
    Added detailed description for Arduino Mega Pro Mini as processing unit.
2026-07-11 Enhance Readme with Arduino Mega Pro Mini details
    Added information about the role of Arduino Mega Pro Mini in the system architecture, highlighting its function as the brain of the robot and its interaction with various sensors.
2026-07-11 Add image for HC-SR04 sensor explanation
    Added an image to enhance the explanation of the HC-SR04 sensors.
2026-07-11 Revise HC-SR04 sensor description in Readme
    Updated the description of the HC-SR04 ultrasonic sensors, clarifying their function and integration in the vehicle's navigation logic.
2026-07-11 Enhance Readme with Arduino Mega Pro Mini details
    Added detailed description of the Arduino Mega Pro Mini as the selected development board, highlighting its advantages in size, connectivity, and cost-effectiveness.
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2026-08-04 Fix image source for esp32cam in Readme.md
2026-08-04 Fix image source in Readme.md for esp32cam
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2026-08-04 Update Readme with new LED entries
    Added entries for 'led rojo' and 'led azul' with images.
2026-08-04 Expand Readme with electronic connection details
    Added detailed explanations of electronic connections, power stage components, and additional sensors used in the project.
2026-08-04 Add HC-SR04 sensor image to Readme
    Added an image of the HC-SR04 sensor to the documentation.
2026-08-04 Update Readme with images for components
    Added images for L298N and HC-SR04 sensors to the documentation.
2026-08-04 Fix duplicate image tag in Readme.md
    Removed duplicate image tag for HC-SR04 sensor.
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2026-09-11 Fix image formatting and update LED connections
    Updated images and formatting in the Readme file.
